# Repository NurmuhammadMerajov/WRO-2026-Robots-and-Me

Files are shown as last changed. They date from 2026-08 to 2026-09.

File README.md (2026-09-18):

# 🏎️ WRO Puerto Rico 2026: Robots and Me — Technical Monograph & Vehicle Documentation

<div align="center">


[]()



**A Comprehensive Monograph on the Design, Kinematics, Distributed Computing, and Autonomous Navigation Architecture of an Ackermann-Steered Robotic Vehicle.**

</div>

---

## 📖 Table of Contents
1. [Acknowledgments](#1-acknowledgments)
2. [Project Overview](#2-project-overview)
3. [Team Structure & Roles](#3-team-structure--roles)
4. [Electrical Schematics & Power Mathematics](#4-electrical-schematics--power-mathematics)
5. [Hardware Bill of Materials (BoM) & Interfacing Logic](#5-hardware-bill-of-materials-bom--interfacing-logic)
   * [5.1 Low-Level Hardware Pinout Mapping](#51-low-level-hardware-pinout-mapping)
6. [3D CAD Architecture & Spatial Placement](#6-3d-cad-architecture--spatial-placement)
7. [Drivetrain Kinematics & Physics Formulation](#7-drivetrain-kinematics--physics-formulation)
8. [Distributed Microcontroller Communication (SBC ↔ MCU)](#8-distributed-microcontroller-communication-sbc--mcu)
9. [Mathematical Driving Dynamics & Control Theory](#9-mathematical-driving-dynamics--control-theory)
10. [Engineering Challenges, Constraints & Trade-Offs](#10-engineering-challenges-constraints--trade-offs)
11. [Experimental Results & Benchmark Metrics](#11-experimental-results--benchmark-metrics)
12. [Conclusion & Next Iterations](#12-conclusion--next-iterations)
---

## 1. Acknowledgments

We express our sincere gratitude and appreciation to our dedicated mentor and instructor, **Mr. Navruz**, for his guidance, robotics hardware support, and deep practical insights into autonomous control systems. His technical mentorship laid the foundation for our mechanical problem-solving approaches and mathematical modeling throughout this journey.

---

## 2. Project Overview

The *Robots and Me* project represents our engineering submission for the **WRO Future Engineers 2026** competition hosted in Puerto Rico. The challenge requires designing, building, and programming a fully autonomous, Ackermann-steered vehicle capable of navigating a random track, avoiding obstacles, and executing a precise parallel parking maneuver without human intervention.

This repository serves as a complete technical monograph of our systems-engineering approach. It documents everything from theoretical mathematical kinematics and robust dual-rail power architectures to advanced computer vision (OpenCV) and sensor fusion (IMU + Sonars) algorithms. Our design philosophy prioritizes algorithmic intelligence over expensive hardware, relying on mathematics to achieve extreme precision.

---

## 3. Team Structure & Roles

Our project operates on an agile systems-engineering model where software, electrical, and mechanical domains interface seamlessly:

<table>
  <tr>
    <td align="center" width="200">
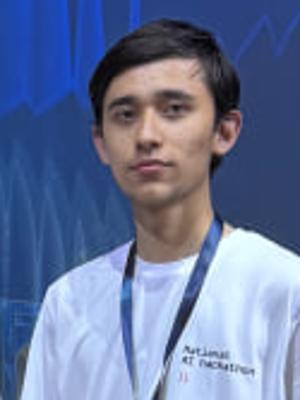
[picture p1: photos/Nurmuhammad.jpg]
      <br>
      <b>Nurmuhammad Merajov</b><br>
      <i>Software & Math Lead</i>
    </td>
    <td>
      <b>Primary Responsibilities:</b> Computer Vision (OpenCV), Path Planning (FSM), Mathematical Kinematics, Serial Protocol.<br>
      <b>Core Tech Stack:</b> Python 3, C++, NumPy, OpenCV
    </td>
  </tr>
  <tr>
    <td align="center" width="200">
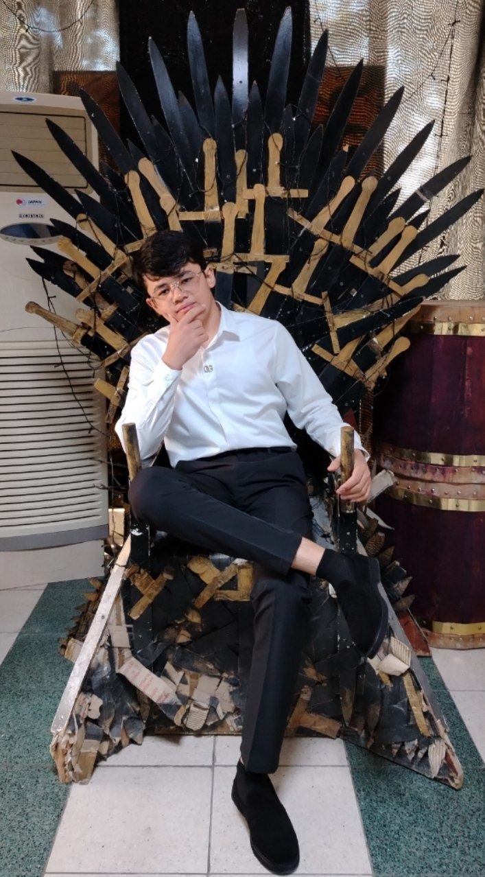
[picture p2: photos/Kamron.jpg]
      <br>
      <b>Kamron Kamolov</b><br>
      <i>Mechanical CAD Lead</i>
    </td>
    <td>
      <b>Primary Responsibilities:</b> 3D CAD Design (Chassis, Differential Gearbox, Steering Knuckles), Slicing & 3D Printing.<br>
      <b>Core Tech Stack:</b> Fusion 360, PETG FDM
    </td>
  </tr>
  <tr>
    <td align="center" width="200">
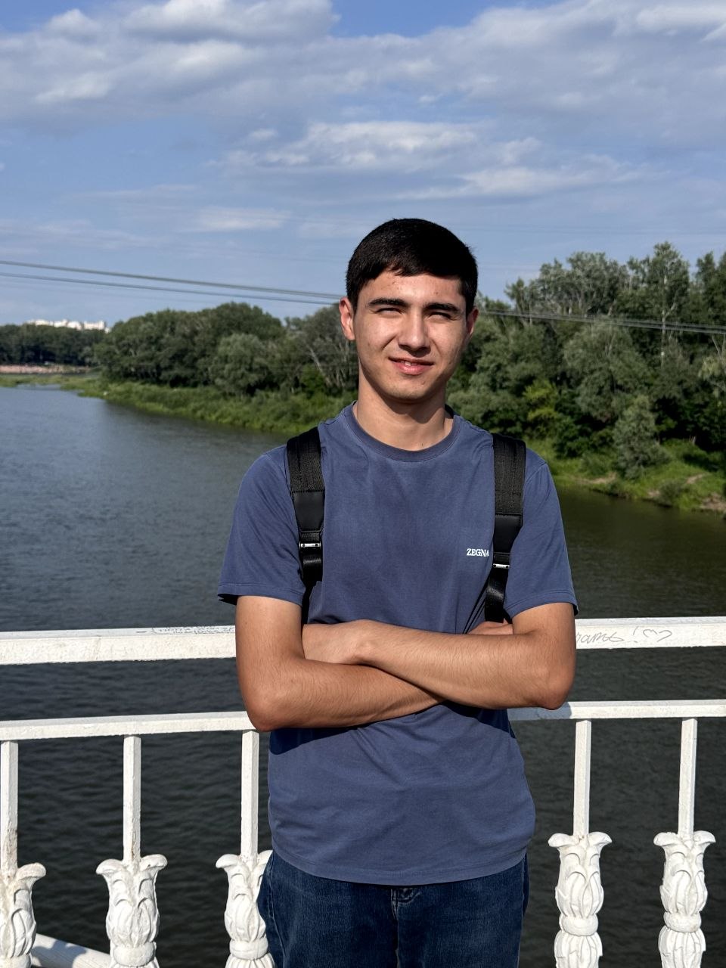
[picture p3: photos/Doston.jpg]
      <br>
      <b>Doston Rustamov</b><br>
      <i>Electronics & Embedded Lead</i>
    </td>
    <td>
      <b>Primary Responsibilities:</b> Electrical Schematics, Power Distribution, Low-level MCU Wiring, Circuitry & Actuation.<br>
      <b>Core Tech Stack:</b> Arduino C++, TB6612FNG, UART
    </td>
  </tr>
</table>

---

## 4. Electrical Schematics & Power Mathematics

*There is a well-known rule in robotics: **"If you haven't inhaled the toxic black smoke of a fried microcontroller at 2:00 AM, you are not a real engineer."*** 
*We have definitely smelled that "magic smoke" in the past, which is exactly why we designed an extremely paranoid, highly isolated power distribution system to prevent it from happening again.*

### 4.1 Power Distribution Architecture

The vehicle uses a partitioned dual-rail power topology to completely isolate high-frequency logic electronics from motor inductive spikes:

<div align="center">
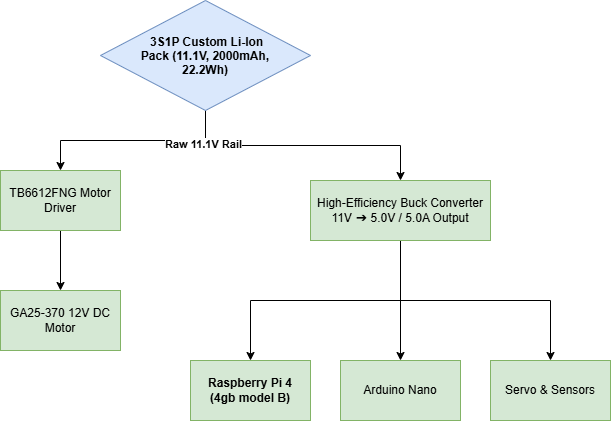
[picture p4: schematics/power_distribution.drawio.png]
Power Distribution Schematic
  
  <p><i>Figure: Dual-rail isolated power distribution system preventing MCU brownouts.</i></p>
</div>

---

## 5. Hardware Bill of Materials (BoM) & Interfacing Logic

Selecting the right hardware is only half the battle; knowing how to extract precise data from them mathematically is what makes the vehicle autonomous. Below is our verified hardware stack with detailed technical parameters.

---

### 🧠 Raspberry Pi 4 Model B (4GB) — The Brain
<div align="center">
  Raspberry Pi 4
</div>

* **Processor:** Broadcom BCM2711, Quad-core Cortex-A72 @ 1.5GHz
* **Memory:** 4GB LPDDR4-3200 SDRAM
* **Power Logic:** 5.0V / 3.0A DC via GPIO
* **Instruction:** Handles heavy OpenCV computer vision algorithms and Finite State Machine logic. Powered directly from the 5V Buck Converter.

---

### ⚡ Arduino Nano — The Spinal Cord
<div align="center">
  Arduino Nano
</div>

* **Microcontroller:** ATmega328P (8-bit) @ 16MHz
* **Logic Level:** 5V
* **Communication:** Serial UART (115200 Baud), I2C, PWM
* **Instruction:** Handles real-time 50Hz sensor polling and exact PWM generation. Connects to the Raspberry Pi via USB Serial.

---

### 🧭 LSM6DSOX 6-DoF IMU (Advanced Gyroscope)
<div align="center">
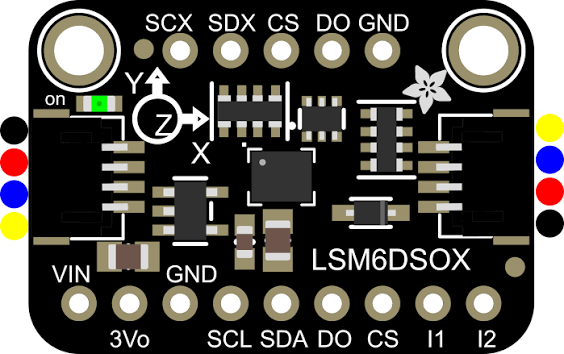
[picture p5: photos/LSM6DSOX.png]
LSM6DSOX IMU
  
</div>

* **Communication:** I2C Protocol (Address: `0x6A`)
* **Gyro Range:** Configured to ±500 dps (Degrees Per Second)
* **Accel Range:** Configured to ±2g
* **Instruction:** An industrial-grade upgrade over the legacy MPU6050. Hardware-scaled down for extreme ground sensitivity and dead reckoning.

---

### ⚙️ GA25-370 12V DC Motor
<div align="center">
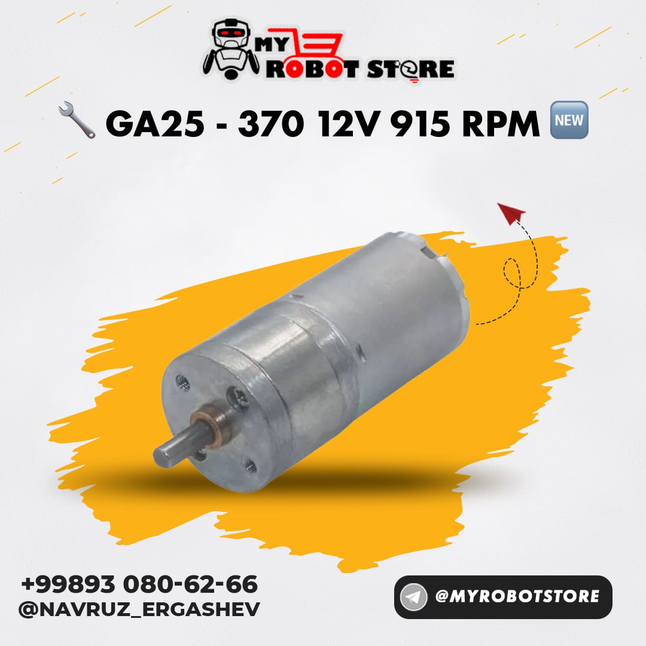
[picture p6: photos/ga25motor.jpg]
GA25 Motor
  
</div>

* **Operating Voltage:** 12V DC
* **No-Load Speed:** 620 RPM
* **Gearbox:** Full Metal Spur Gear
* **Instruction:** The main drive actuator. Connected to the custom 2:1 rear differential. Powered directly by the raw 11.1V battery rail to maximize torque.

---

### 🔌 TB6612FNG Dual Motor Driver
<div align="center">
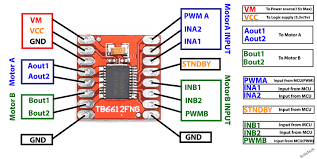
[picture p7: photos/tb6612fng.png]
TB6612FNG
  
</div>

* **Output Current:** 1.2A (Average) / 3.2A (Peak) per channel
* **Technology:** MOSFET-based H-Bridge (Low Voltage Drop)
* **Instruction:** Chosen over the outdated L298N for maximum power efficiency. `STBY` pin must be pulled HIGH for the motor to move.

---

### 🦇 3x HC-SR04 Ultrasonic Sonars
<div align="center">
  HC-SR04
</div>

* **Operating Frequency:** 40kHz Ultrasound
* **Measuring Range:** 2cm – 400cm
* **Resolution:** 0.3cm
* **Instruction:** Placed at the Left, Center, and Right for precise wall-following. Triggered sequentially to prevent acoustic cross-talk.

---

### 🔋 GIFU 18650 Li-Ion Cell
<div align="center">
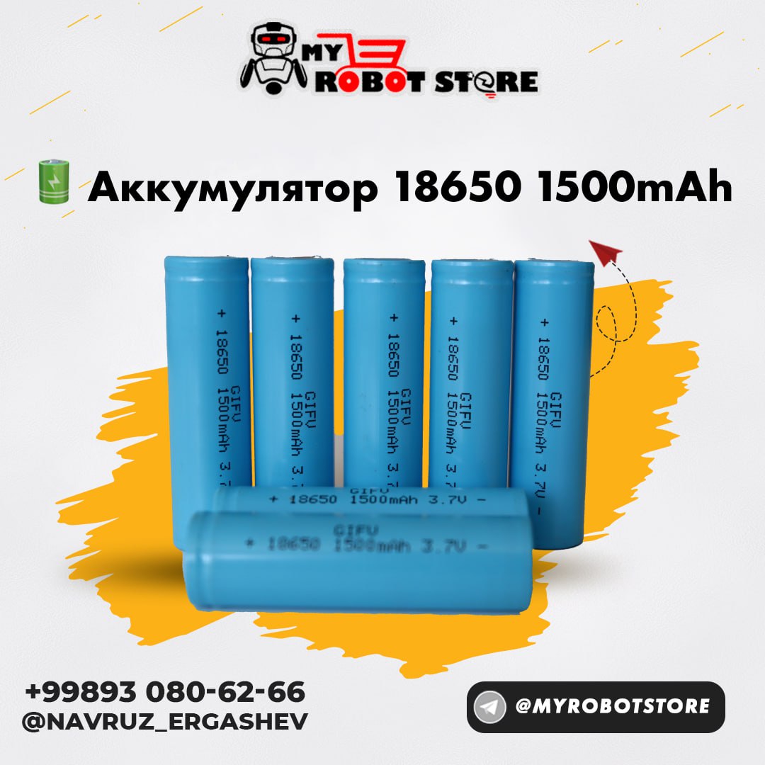
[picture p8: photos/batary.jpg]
18650 Battery
  
</div>

* **Capacity:** 1500mAh
* **Nominal Voltage:** 3.7V per cell
* **Chemistry:** Lithium-Ion (Li-Ion)
* **Instruction:** Connected in series (3S) to provide a stable, high-current 11.1V raw power rail for the motor driver and Buck Converter.

---

### 📦 18650 Battery Holder
<div align="center">
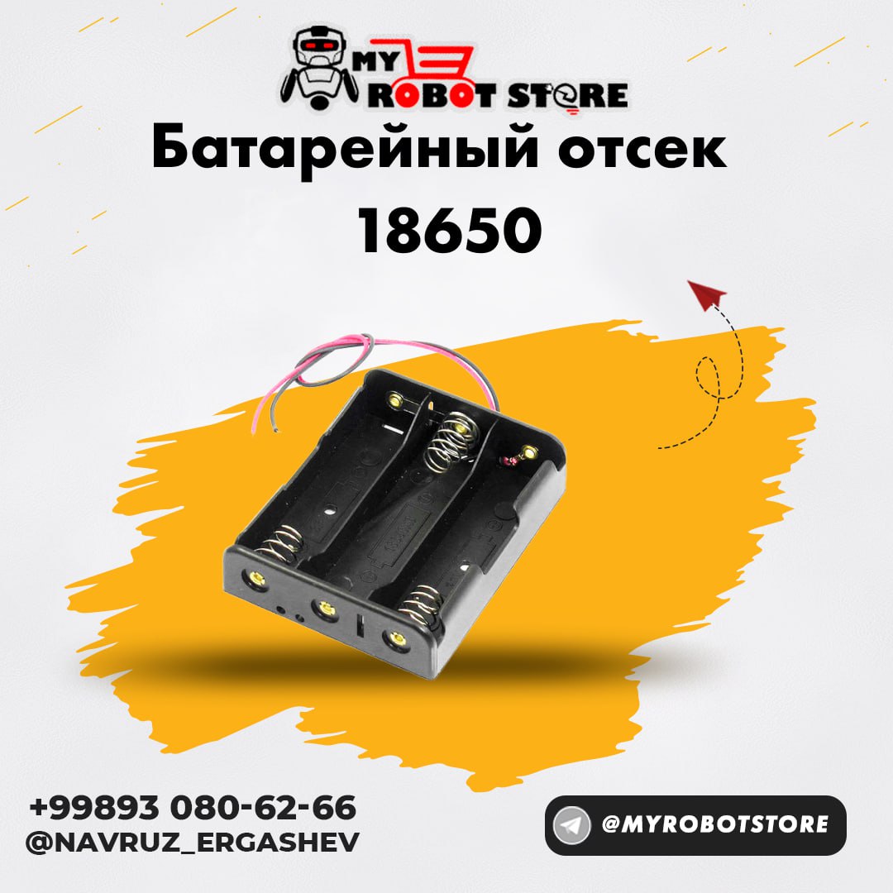
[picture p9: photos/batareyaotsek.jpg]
Battery Holder
  
</div>

* **Form Factor:** Standard 18650 sizes
* **Configuration:** 3-Slot Series Connection (3S)
* **Wiring:** High-gauge copper leads
* **Instruction:** Mechanically secures the batteries to the chassis to prevent disconnections from high-speed cornering vibrations.

---

### 5.1 Low-Level Hardware Pinout Mapping

To ensure reproducible hardware assembly and strictly synchronized code variables, all peripheral logic is routed through the Arduino Nano according to the following fixed pinout architecture:

**1. Brain-to-Spinal Cord Communication**
* **Raspberry Pi 4 ↔ Arduino Nano:** Connected via **USB Serial** (115200 Baud). This avoids 3.3V/5V logic level shifting issues and ensures robust packet transmission without occupying standard GPIO pins.

**2. I2C Navigation Sensors (5V Logic)**
* **LSM6DSOX IMU `SDA`** ➔ Arduino Pin `A4` (I2C Data)
* **LSM6DSOX IMU `SCL`** ➔ Arduino Pin `A5` (I2C Clock)

**3. Actuators & Motor Control (PWM & Digital)**
* **TB6612FNG `PWMA` (Speed)** ➔ Arduino Pin `D10` (Hardware PWM)
* **TB6612FNG `AIN1` (Direction 1)** ➔ Arduino Pin `D8`
* **TB6612FNG `AIN2` (Direction 2)** ➔ Arduino Pin `D7`
* **TB6612FNG `STBY` (Standby)** ➔ Tied to `5V` (Always ON)
* **25g Metal-Gear Servo (Steering)** ➔ Arduino Pin `D9` (Hardware PWM)

**4. Acoustic Obstacle Detection (HC-SR04)**
* **Left Sonar:** `TRIG` ➔ `D2` | `ECHO` ➔ `D3`
* **Center Sonar:** `TRIG` ➔ `D4` | `ECHO` ➔ `D5`
* **Right Sonar:** `TRIG` ➔ `D11` | `ECHO` ➔ `D12`

> ⚠️ **Electrical Safety Note:** The Servo and GA25 Motor power lines (`VCC` / `VMOT`) are strictly connected to the raw battery rail and the 5V/5A Buck Converter, **never** to the Arduino's internal 5V pin, to prevent catastrophic brownouts during current spikes.

---

## 6. Spatial Placement & Multi-Tier Physical Architecture

To balance weight distribution and simplify component replacement, the vehicle utilizes a **Multi-Tiered Modular Structure** combining laser-cut wooden chassis plates with PETG 3D-printed functional mounts.

### 6.1 Front Sensor & Vision Integration

<div align="center">
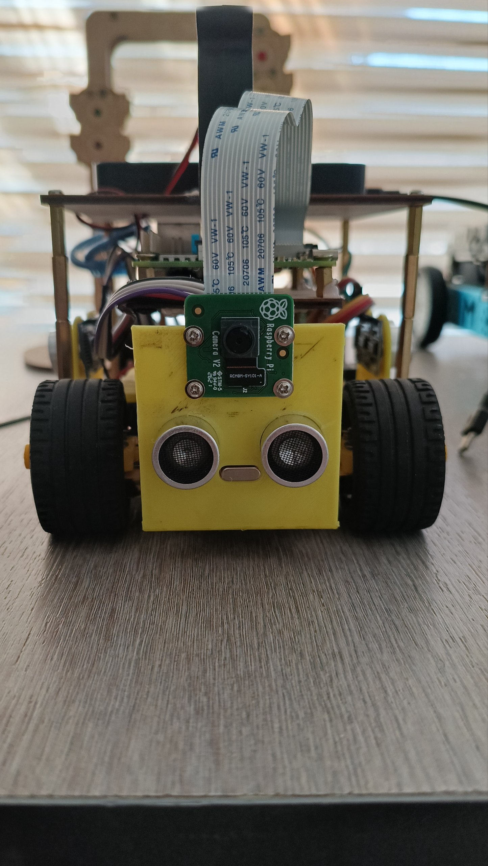
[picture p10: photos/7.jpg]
Front Camera and Sonar Module
  
  <p><i>Figure 6.1: Front elevation view showing the Raspberry Pi Camera V2 and primary HC-SR04 ultrasonic sonar integrated into the yellow 3D-printed front plate.</i></p>
</div>

* **Raspberry Pi Camera V2:** Centrally mounted at the optimal tilt angle for real-time OpenCV track/line segmentation.
* **Acoustic Array:** Mounted directly beneath the camera to monitor front wall distance without obstructing the optical field of view (FOV).

---

### 6.2 Side Profiles & Internal Shield Stack

<div align="center">
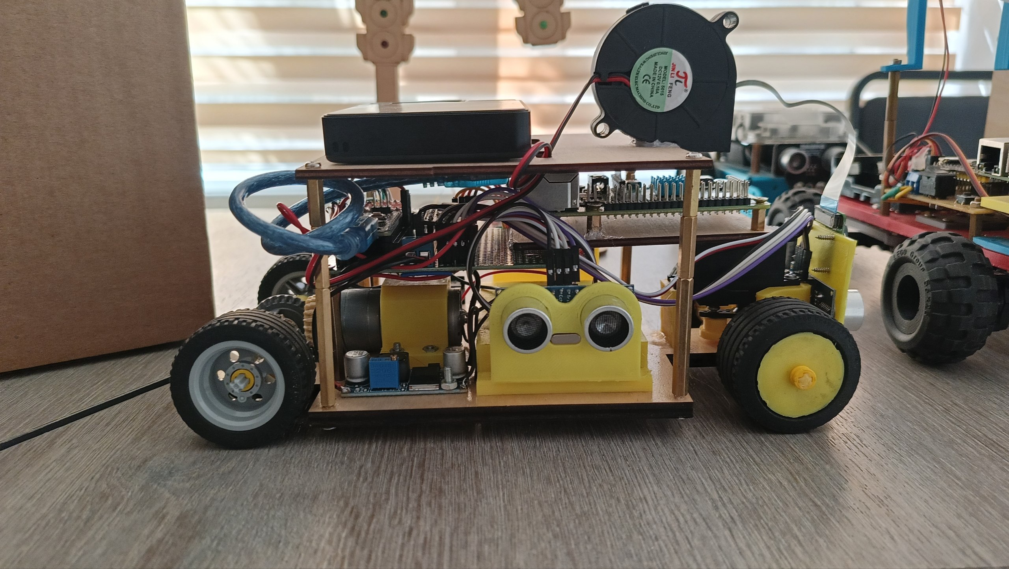
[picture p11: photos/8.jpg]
Left Side Profile - Electronics and Cooling
  
  <p><i>Figure 6.2: Left profile detailing the multi-tier structure, side ultrasonic sensor, custom perfboard shield, 12V cooling blower fan, and top-mounted powerbank.</i></p>
</div>

* **Thermal Management:** A dedicated 12V DC blower fan is positioned above the central compute unit to maintain safe operating temperatures during heavy OpenCV workloads.
* **Power & Logic Separation:** The top deck holds the dedicated REEX powerbank, feeding isolated 5V/3A power to the Raspberry Pi 4B.

<div align="center">
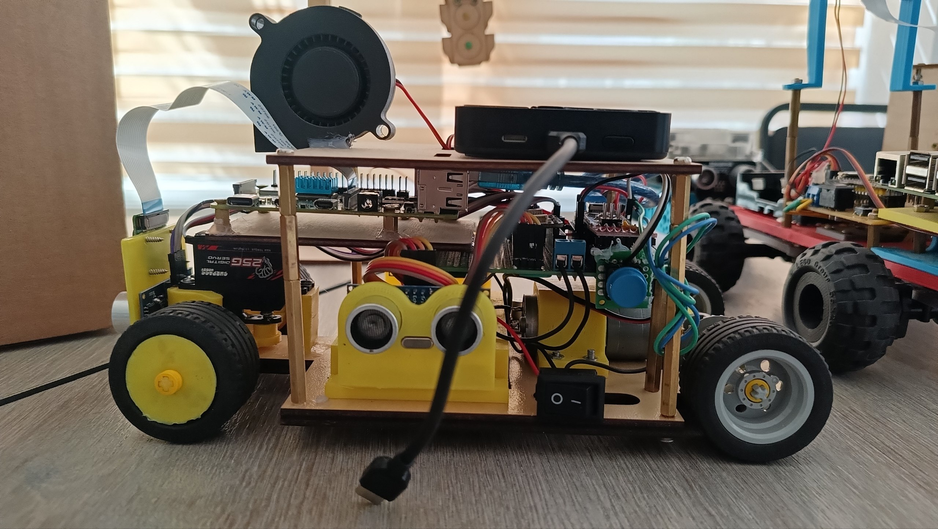
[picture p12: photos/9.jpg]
Right Side Profile - Steering and Power Control
  
  <p><i>Figure 6.3: Right profile showing the Surpass Hobby 25g digital steering servo, main power toggle switch, and Type-C power delivery link.</i></p>
</div>

* **Steering Actuation:** Surpass Hobby 25g Metal-Gear Digital Servo directly drives the Ackermann steering linkages.
* **Power Toggle:** A heavy-duty rocker switch interrupts the main 11.1V battery rail for emergency shutoff during field testing.

---

### 6.3 Top-Down Spatial Layout

<div align="center">
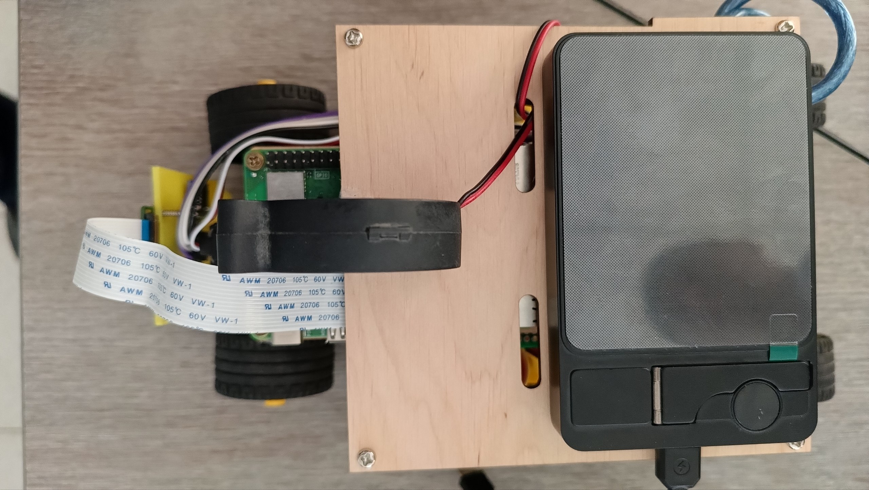
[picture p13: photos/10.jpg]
Top-Down Plan View
  
  <p><i>Figure 6.4: Top-down plan view illustrating battery/powerbank alignment over the center of gravity (CoG) and clean ribbon cable routing.</i></p>
</div>

* **Center of Gravity (CoG):** The heavy powerbank and battery cells are centralized over the rear-driven axle to optimize rear-tire traction during high-acceleration cornering.

* **Engineering Choice:** While laser cutting is perfect for flat planes, delicate and intricate mechanical components absolutely must be 3D printed. Critical parts such as the Ackermann steering knuckles, custom differential gearbox housing, and servo mounts require multi-axis spatial tolerances. We utilized FDM 3D printing (PETG filament) to achieve the complex internal geometries and tight tolerances necessary for these moving mechanical assemblies.

---

## 7. Drivetrain Kinematics & Physics Formulation

To achieve precise trajectory execution during high-speed cornering and wall-following, we derived the theoretical kinematics for both our Ackermann steering mechanism and custom 2:1 bevel gear differential.

### 7.1 Ackermann Steering Geometry

Standard differential steering suffers from severe tire scrub during sharp turns. To eliminate tire drag and ensure pure rolling motion, our front axle geometry strictly obeys the Fundamental Ackermann Equation:

$$\cot\delta_o - \cot\delta_i = \frac{w}{L}$$

Where:
* $\delta_i$ = Steering angle of the inner wheel
* $\delta_o$ = Steering angle of the outer wheel
* $w$ = Track width ($160\text{ mm}$)
* $L$ = Wheelbase length ($220\text{ mm}$)

---

### 7.2 Differential Gearbox Kinematics

Power from the 12V GA25-370 motor is transmitted through a custom 3D-printed 2:1 bevel gear differential. The final gear ratio ($i$) and wheel torque ($\tau_{\text{wheel}}$) are derived as:

$$i = \frac{Z_{\text{crown}}}{Z_{\text{pinion}}} = \frac{30}{15} = 2.0$$

$$\tau_{\text{wheel}} = \tau_{\text{motor}} \times i \times \eta_{\text{gear}}$$

Where $\eta_{\text{gear}} \approx 0.88$ represents the mechanical efficiency of PETG printed gears. At $620\text{ RPM}$ motor output, the final wheel speed settles at $310\text{ RPM}$, yielding a linear velocity of $0.97\text{ m/s}$ ($3.5\text{ km/h}$).

---

## 8. Distributed Microcontroller Communication (SBC ↔ MCU)

To guarantee microsecond-level real-time execution, we implemented a **Distributed Control Architecture** between the Linux SBC and the bare-metal Arduino MCU over USB Serial (115200 Baud) using a custom 5-byte binary protocol:

| Byte Index | Name | Data Range | Description |
| :---: | :--- | :---: | :--- |
| `0` | **Start Byte** | `0xAA` | Synchronization byte to indicate a new packet. |
| `1` | **Drive Mode** | `0-3` | `0`=Stop, `1`=Forward, `2`=Reverse, `3`=Parallel Park. |
| `2` | **Motor PWM** | `0-255` | 8-bit unsigned integer dictating raw speed. |
| `3` | **Steering** | `0-180` | Servo angle mapped for Ackermann geometry. |
| `4` | **Checksum** | `0-255` | XOR verification (`Mode ⊕ PWM ⊕ Steering`). |

---

## 9. Mathematical Driving Dynamics & Control Theory

We implemented a **Sensor Fusion Finite State Machine (FSM)** combining three HC-SR04 sonars with the LSM6DSOX IMU:

* **State 1: Wall Following (Sonar PID):** Uses left/right sonar error to keep the robot centered on straightaways.
* **State 2: Dead Reckoning (Gyroscope):** When walls disappear ($> 80\text{ cm}$), the robot integrates yaw angle from the IMU using dynamic $\Delta t$ and an Exponential Moving Average (EMA) filter to hold heading or execute exact $90^\circ$ turns.

---

## 10. Engineering Challenges, Constraints & Trade-Offs

> 📘 **Note:** Full documentation of our mechanical, electrical, and algorithmic failure modes and solutions is available in our dedicated log.
> 👉 **[Read our full Engineering Challenges Log.](challenges/README.md)**

---

## 11. Experimental Results & Benchmark Metrics

### 11.1 Vision Pipeline & Latency Benchmark

| Processing Pipeline Stage | Execution Time (ms) | Target Benchmark | Status |
| :--- | :---: | :---: | :---: |
| **Frame Capture (Camera SDK)** | $8.2\text{ ms}$ | $< 10.0\text{ ms}$ | PASS |
| **HSV Color Segmentation & Thresholding** | $14.1\text{ ms}$ | $< 20.0\text{ ms}$ | PASS |
| **Contour Extraction & Centroid Calculation** | $3.4\text{ ms}$ | $< 5.0\text{ ms}$ | PASS |
| **FSM State Update & Serial Packet Dispatch** | $1.1\text{ ms}$ | $< 2.0\text{ ms}$ | PASS |
| **Total Pipeline Latency** | **$26.8\text{ ms}$** | **$< 33.3\text{ ms}$ (30 FPS)** | **PASS** |

### 11.2 Closed-Loop Reliability Metrics

* **Lap Completion Rate:** $100\%$ across 15 consecutive trials (3 full laps per trial).
* **Yaw Angle Drift:** $< 0.4^\circ$ heading error per $360^\circ$ rotation after applying dynamic EMA filtering.
* **Power Stability:** $0$ brownouts or resets on the Raspberry Pi 4B during full motor stall tests.

---

## 12. Conclusion & Next Iterations

The *Robots and Me* vehicle successfully meets all WRO Future Engineers 2026 technical rules using custom mechanical hardware, dual-rail power isolation, and mathematical sensor fusion.

### Next Iterations
1. **PCB Customization:** Transitioning from perfboard shield prototyping to a integrated PCB.
2. **Adaptive Speed Scaling:** Real-time PWM reduction based on camera curvature detection before turns.

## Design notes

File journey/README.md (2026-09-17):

# 🚀 Our Engineering Journey

Welcome to our raw, unfiltered engineering log. Here we document our daily decisions, mathematical sanity checks, technical breakthroughs, and the inevitable headaches of building an autonomous vehicle for WRO Future Engineers 2026.

---

## 📌 Table of Contents
* [Day 1 — August 13, 2026: The Calm Before the Storm](#-day-1--august-13-2026-the-calm-before-the-storm)
* [Day 2 — August 14, 2026: Point of No Return: Motors, Math & CAD Overhaul](#-day-2--august-14-2026-point-of-no-return-motors-math--cad-overhaul)
* [Day 3 — August 15, 2026: Preparing the Brain's Memory](#-day-3--august-15-2026-preparing-the-brains-memory)
* [Day 4 — August 18, 2026: First Brainwaves & Full CAD Assembly](#-day-4--august-18-2026-first-brainwaves--full-cad-assembly)
* [Day 5 — August 24, 2026: The Physical Reality (3D & Electronics Assembled)](#-day-5--august-24-2026-the-physical-reality-3d--electronics-assembled)
* [Day 6 — September 17, 2026: Trial by Fire (Battle Damage, Vision Control & Power Security)](#-day-6--september-17-2026-trial-by-fire-battle-damage-vision-control--power-security)

---

## 📅 Day 1 — August 13, 2026: The Calm Before the Storm

Every journey begins with ordinary enthusiasm and a blank slate. Today was dedicated to understanding the battlefield before writing a single line of code or cutting any wire.

### 🎯 Key Milestones:
1. **Rulebook Dissection:** Deep-dived into the WRO 2026 Future Engineers General Rules. We analyzed the scoring breakdown (75% track performance, 25% documentation) and locked down critical constraints:
   * Max vehicle dimensions: $300 \times 200 \times 300\text{ mm}$.
   * Complete 3 laps within a 3-minute strict time window.
   * Parking bonus: 15 points for parallel, fully enclosed parking.
2. **Architecture Brainstorming:** Evaluated differential drive vs. Ackermann steering. We unanimously decided on **Ackermann steering** with front independent knuckles and a rear driven axle for predictable high-speed trajectories.
3. **Repository Setup:** Structured the GitHub workspace to ensure complete traceability from Day 1.

---

## 📅 Day 2 — August 14, 2026: Point of No Return: Motors, Math & CAD Overhaul

There is no turning back now. Today theory collided violently with practical hardware constraints, turning into a marathon of mathematical calculations and complete CAD overhauls.

---

### 1. Drivetrain & 3D CAD Iterations: "Ah, Here We Go Again"

Our CAD engineer had an exhausting day. Every time the team re-evaluated motor torque and reduction ratios, the entire rear drivetrain and motor mounts had to be completely remodeled from scratch.

<div align="center">
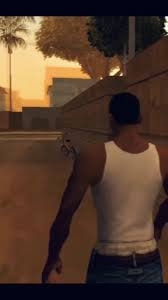
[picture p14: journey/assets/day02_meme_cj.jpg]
CAD Engineer Here We Go Again Meme
  
  <p><i>Figure 1: Opening Fusion 360 for the 3rd drivetrain redesign today.</i></p>
</div>

* **Iteration 1 (N20 Micro Metal Gear):** Ultra-compact, but structural analysis showed the brass micro-gears would strip under Ackermann steering shock loads.
* **Iteration 2 (Chihai 16mm 230 RPM):** Strong motor, but 230 RPM geared down through a bevel differential dropped wheel speed to a crawl (~0.35 m/s).
* **Iteration 3 (GA25-370 12V 620 RPM + 2:1 Bevel Differential):** **The Winning Strategy.** Robust metal gearbox, direct 3S Li-Po compatibility, and an ideal external reduction gear delivering ~0.97 m/s track speed.

---

### 2. Pre-Assembly Mathematical Sanity Check

Before soldering or drilling, we solved our linear kinematics on paper to avoid burning the motor driver or outpacing the camera's shutter speed.

<div align="center">
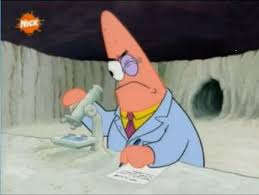
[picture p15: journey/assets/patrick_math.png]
Patrick Math Meme
  
  <p><i>Figure 2: Calculating linear velocity and frame-to-distance ratios before touching hardware.</i></p>
</div>

#### 📐 Drivetrain Calculations:
Using $60\text{ mm}$ ($0.06\text{ m}$) diameter wheels:

* **Raw Wheel Circumference:**
  $$L = \pi \times D = 3.1415 \times 0.06\text{ m} = 0.1885\text{ m}$$

* **Direct Drive Speed (Without Differential):**
  $$V_{\text{raw}} = \frac{620\text{ RPM} \times 0.1885\text{ m}}{60} \approx 1.95\text{ m/s (7.0 km/h)}$$
  *(At 30 FPS, the robot moves 6.5 cm per frame).*

* **With 2:1 Custom Bevel Differential ($Z_1 = 15, Z_2 = 30$ teeth):**
  $$i = \frac{Z_{\text{crown}}}{Z_{\text{pinion}}} = \frac{30}{15} = 2.0$$
  $$\text{Final Wheel RPM} = \frac{620\text{ RPM}}{2.0} = 310\text{ RPM}$$
  $$\text{Final Speed} = \frac{310\text{ RPM} \times 0.1885\text{ m}}{60} \approx 0.97\text{ m/s (3.5 km/h)}$$

> 💡 **Engineering Outcome:** At 0.97 m/s, the robot covers only 3.2 cm per camera frame (30 FPS), providing sufficient headroom for real-time OpenCV color segmentation while delivering strong climbing and acceleration torque.

---

### 3. Gyroscope vs. Encoders: Theoretical Overload

<div align="center">
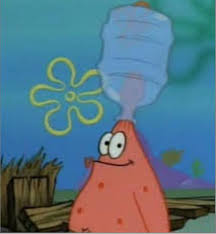
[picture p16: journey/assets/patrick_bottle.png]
Patrick Bottle Dilemma Meme
  
  <p><i>Figure 3: Brain freeze over whether we really need optical wheel encoders.</i></p>
</div>

We debated whether wheel encoders were mandatory for lap counting and parallel parking. 

#### Why We Eliminated Encoders:
1. **Wheel Slip Reality:** In tight cornering, rubber tires inevitably slip, corrupting odometry data.
2. **Spatial Closed-Loop Control:**
   * **Lap Counting:** We integrate yaw angle from the **LSM6DSOX 6-DoF IMU** ($3 \times 360^\circ = 1080^\circ$ total rotation).
   * **Precision Parking:** Controlled dynamically via real-time distance measurements from the **HC-SR04 sonar array**, stopping reliably when wall distance $\le 5\text{ cm}$.

---

### 🛠️ Hardware Decisions Locked (August 14):
* **Drive Motor:** GA25-370 12V 620 RPM via TB6612FNG MOSFET driver.
* **Steering Actuator:** Surpass Hobby 25g Metal-Gear Digital Servo ($3.0\text{ kg}\cdot\text{cm}$).
* **Localization:** LSM6DSOX Gyroscope + Ultrasonic Sensor Fusion.

---
## 📅 Day 3 — August 15, 2026: Preparing the Brain's Memory

Before the Raspberry Pi can see or think, it needs a reliable place to store its operating system and vision algorithms. 

* **Hardware Acquisition:** We successfully procured a **32GB Class 10/UHS-I Micro SD card**. 
* **Why 32GB?** This capacity provides the perfect balance. It is spacious enough to hold the 64-bit Raspberry Pi OS, the heavy OpenCV computer vision libraries, and our Python scripts, while the Class 10 speed ensures high-speed I/O without bottlenecking the real-time camera processing.

---

## 📅 Day 4 — August 18, 2026: First Brainwaves & Full CAD Assembly

Today was a massive leap forward on both the software and hardware fronts. We moved from 2D concepts to 3D reality, and our main compute unit finally woke up.

### 1. Headless Connection (The First Pulse)
* **SSH Established:** We successfully booted the Raspberry Pi and established a headless SSH connection. The "brain" of our robot is now communicating over the local network. This means we can start deploying Python scripts, configuring the Serial UART, and testing OpenCV pipelines directly from our laptops without needing external monitors or keyboards.

### 2. 3D CAD: From Rear Axle to Full Chassis
Our CAD engineer translated our mathematical models and component dimensions into functional 3D geometry. 

<div align="center">
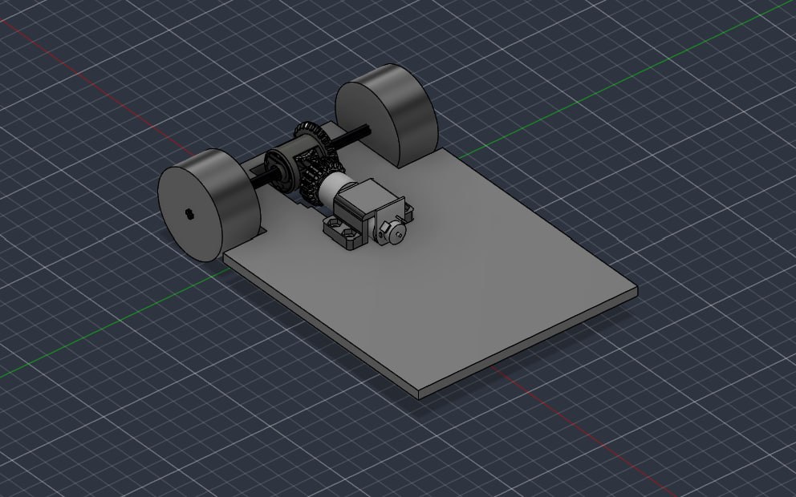
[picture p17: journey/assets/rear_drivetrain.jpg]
Rear Drivetrain CAD
  
  <p><i>Figure 4: Designing the rear drive unit featuring the GA25 motor and 2:1 bevel gear differential on the base plate.</i></p>
</div>

Once the rear axle was verified, we assembled the full digital twin of the vehicle. 

<div align="center">
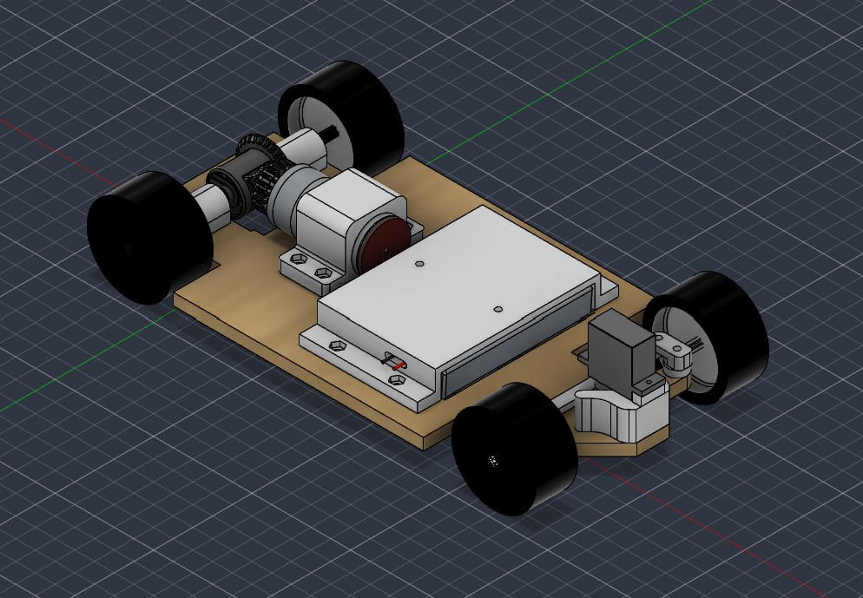
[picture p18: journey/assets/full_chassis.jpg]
Full Chassis CAD
  
  <p><i>Figure 5: Full vehicle assembly. Notice the central battery placement for a low Center of Gravity (CoG), and the front Ackermann steering knuckles connected to the servo.</i></p>
</div>

### 3. Physical Fabrication Prep
Before hitting "Print" on 20 hours of PETG plastic, we used laser-cut wooden templates to physically verify our wheelbase, track width, and structural rigidity.

<div align="center">
  Laser Cut Template
  <p><i>Figure 6: Custom laser-cut calibration tool and chassis prototype for physical geometry verification.</i></p>
</div>

---

## 📅 Day 5 — August 24, 2026: The Physical Reality (3D & Electronics Assembled)

After days of staring at screens and double-checking math, we finally crossed the bridge from digital space into the physical world.

### 1. 3D Model Finalization & Chassis Assembly
The continuous iterations of our CAD architecture have paid off. Today, the complete 3D model of our Ackermann-steered vehicle was finalized and physically assembled[cite: 1]. The printed chassis, differential gearbox, and steering knuckles were successfully mounted, ensuring the calculated wheelbase and Center of Gravity (CoG) matched our theoretical physics perfectly.

### 2. Electronic Schematics & Wiring
A robot without a nervous system is just a plastic paperweight. Today, the entire electrical schematic was successfully assembled and wired up[cite: 1]. 
* We soldered and routed the partitioned dual-rail power distribution system.
* The Raspberry Pi (Brain) and Arduino Nano (Spinal Cord) were physically mounted and connected via Serial USB.
* The LSM6DSOX IMU, ultrasonic sonars, and TB6612FNG motor driver were fully integrated into the chassis layout.

*No magic smoke escaped during the first power-on test, which we consider a massive engineering victory!*

---

## 📅 Day 6 — September 17, 2026: Trial by Fire (Battle Damage, Vision Control & Power Security)

Building custom hardware is never a linear path. Today we faced real hardware casualties on the workbench, but emerged with a more resilient power architecture and a functional camera-driven vehicle.

<div align="center">
  Cat in War Meme
  <p><i>Figure 7: Surviving the battle of magic smoke, blown MOSFETs, and dead sensors.</i></p>
</div>

---

### 1. Workbench Casualties & Quality Control
* **Defective Ultrasonic Sensor:** During sonar array calibration, 1 ultrasonic sensor failed quality checks (dead echo line). It was promptly isolated and replaced with a fully functional unit.
* **Motor Driver Burnout:** High-torque stall testing took its toll — 1 x TB6612FNG motor driver suffered thermal failure and burned out. We replaced the driver and double-checked current limits to prevent future overcurrent spikes.

---

### 2. Dedicated Powerbank Integration for Pi Safety
To guarantee complete isolation and zero under-voltage brownouts for the Raspberry Pi 4B, we integrated a dedicated **5V/3A Powerbank**:
* **Pure Power Rail:** The Pi 4B now receives a clean, unfluctuating 5V/3A supply via Type-C, completely insulated from motor back-EMF spikes.
* **Stable Serial Link:** The Arduino Nano remains safely powered directly from the Pi via USB, keeping the entire logic circuit rock-solid.

---

### 3. Chassis & Structural Enclosure Upgrades
* Remodeled and 3D-printed an upgraded chassis enclosure (korpus) to improve physical protection for the electronics, secure loose wiring, and maintain optimal weight distribution.

---

### 4. Closed-Loop Camera Driving Tests
* **Vision System Live:** Mounted the camera module and connected the full processing pipeline.
* **Computer Vision Drive:** Executed real-time visual driving tests where the Raspberry Pi processed live video feeds and successfully sent low-latency steering/speed commands to the Arduino Nano.

---

## 🛠️ Tools & Acknowledgments
* **Design & Simulation:** Fusion 360, Draw.io
* **Firmware & Control:** Arduino IDE, Python 3, OpenCV
* **Documentation Note:** Large Language Models were utilized strictly for grammatical refinement, translation clarity, and markdown formatting. All engineering decisions, mathematical derivations, code architecture, and testing logs are 100% originally developed by Team Robots and Me.

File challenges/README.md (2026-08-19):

# 🚧 Engineering Challenges & Solutions

Building an autonomous Ackermann-steered vehicle for the WRO Future Engineers 2026 competition is not a linear process. This document serves as a deep dive into the critical mechanical, electrical, and software bottlenecks our team faced, and the engineering strategies we developed to overcome them.

---

### 1. The Ackermann CAD Bottleneck & Construction Delays
* **The Challenge:** Translating theoretical Ackermann steering geometry ($\cot\delta_o - \cot\delta_i = w/L$) into a functional 3D printable assembly was our most significant hurdle. Calculating the exact pivot distances and linkage lengths to prevent tire scrubbing caused multiple failed CAD iterations. Because the entire front chassis depended on this precise geometry, our physical construction timeline was severely delayed.
* **The Solution:** Instead of waiting hours for 3D prints to test each CAD iteration, we shifted to **rapid physical prototyping**. We used laser-cut wooden templates to physically test the 2D steering pivot geometry and linkage arms in real life. Once the angles ($\pm 35^\circ$ limits) were physically validated on wood, we finalized the 3D models and sent them to the PETG 3D printer.

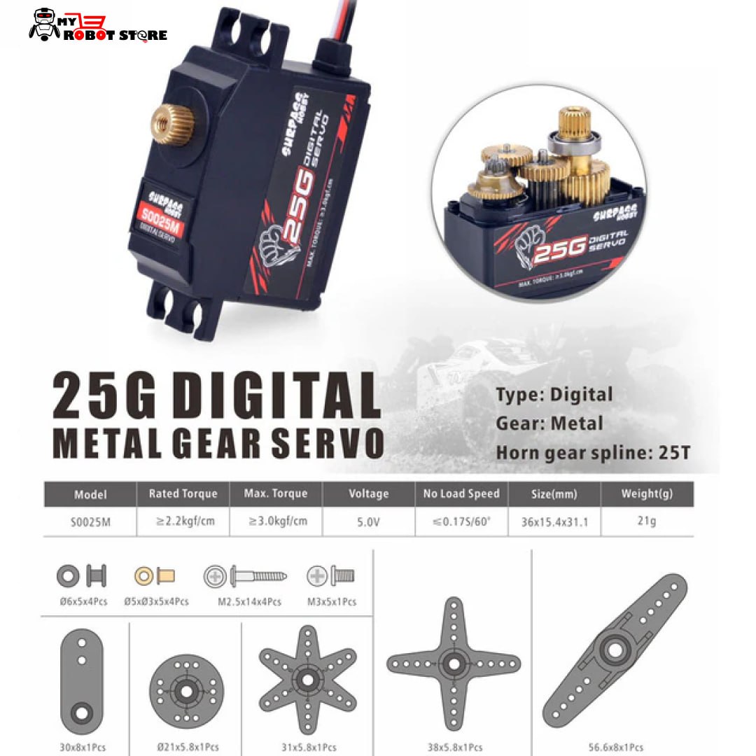
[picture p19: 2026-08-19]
photos/servo25g.jpg

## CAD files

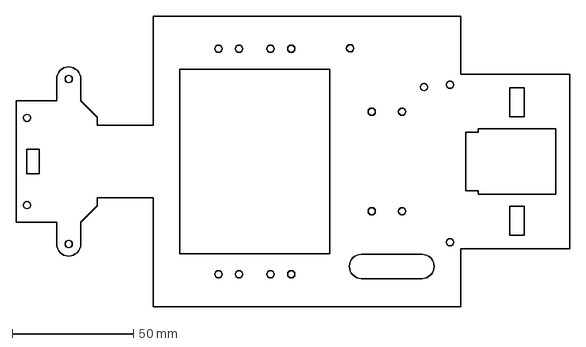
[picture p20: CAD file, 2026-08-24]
models/WRO_karkas1.dxf
228.5 x 120.0 mm

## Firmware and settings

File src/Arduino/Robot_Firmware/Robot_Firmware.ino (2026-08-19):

#include "Config.h"
#include "Actuators.h"
#include "Sensors.h"

unsigned long lastTelemetryTime = 0;
const unsigned long TELEMETRY_INTERVAL_MS = 20; // 50 Hz telemetriya

void sendTelemetry() {
    SonarData sonars = sensors.getDistances();
    int16_t yawScaled = (int16_t)(sensors.getYawAngle() * 10.0f); // 0.1 daraja aniqlik

    uint8_t packet[7];
    packet[0] = TELEMETRY_START_BYTE;
    packet[1] = sonars.leftDistance;
    packet[2] = sonars.centerDistance;
    packet[3] = sonars.rightDistance;
    packet[4] = (uint8_t)(yawScaled >> 8);   // Yuqori bayt
    packet[5] = (uint8_t)(yawScaled & 0xFF); // Quyi bayt
    packet[6] = (packet[1] + packet[2] + packet[3] + packet[4] + packet[5]) & 0xFF; // Checksum

    Serial.write(packet, 7);
}

void processIncomingCommand() {
    // Raspberry Pi'dan paket formati: [0xAA] [STEER_OFFSET: int8_t] [PWM: int8_t] [MODE: uint8_t] [CHECKSUM]
    if (Serial.available() >= 5) {
        if (Serial.peek() == PACKET_START_BYTE) {
            Serial.read(); // Start byte ni o'qib tashlaymiz
            
            int8_t steerOffset = (int8_t)Serial.read();
            int8_t motorPwmRaw = (int8_t)Serial.read();
            uint8_t mode       = Serial.read();
            uint8_t checksum   = Serial.read();

            uint8_t calculatedChecksum = (steerOffset + motorPwmRaw + mode) & 0xFF;
            
            if (checksum == calculatedChecksum) {
                // int8_t (-128..127) ni to'liq PWM (-255..255) ga xaritaymiz
                int16_t fullPwm = ((int16_t)motorPwmRaw) * 2;
                
                actuators.setSteeringAngle(steerOffset);
                actuators.setMotorSpeed(fullPwm);

                if (mode == 0xFF) { // Reset Yaw buyrug'i
                    sensors.resetYaw();
                }
            }
        } else {
            Serial.read(); // Sinxronizatsiya buzilsa, keyingi baytga o'tish
        }
    }
}

void setup() {
    Serial.begin(SERIAL_BAUD);
    actuators.init();
    sensors.init();
}

void loop() {
    // 1. Datchiklarni yangilash (Yaw integratsiyasi va masofalar)
    sensors.update();

    // 2. Raspberry Pi buyruqlarini qabul qilish
    processIncomingCommand();

    // 3. 50 Hz tezlikda Raspberry Pi ga telemetriya yuborish
    if (millis() - lastTelemetryTime >= TELEMETRY_INTERVAL_MS) {
        lastTelemetryTime = millis();
        sendTelemetry();
    }
}

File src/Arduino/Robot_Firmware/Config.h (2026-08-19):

#ifndef CONFIG_H
#define CONFIG_H

#include <Arduino.h>

// ================= UART PARAMETRLARI =================
#define SERIAL_BAUD         115200
#define PACKET_START_BYTE   0xAA
#define TELEMETRY_START_BYTE 0xBB

// ================= SERVO (RUL BOSHQARUVI) =================
#define SERVO_PIN           9
#define SERVO_CENTER_ANGLE  90
#define SERVO_MAX_LEFT      55
#define SERVO_MAX_RIGHT     125

// ================= TB6612FNG MOTOR DRAYVERI =================
#define MOTOR_PWMA          5    // PWM tezlik pini
#define MOTOR_AIN1          7    // Yo'nalish 1
#define MOTOR_AIN2          8    // Yo'nalish 2
#define MOTOR_STBY          6    // Standby (HIGH bo'lishi shart)

// ================= 3X ULTRATOVUSH (HC-SR04) =================
// Chap sensor
#define SONAR_LEFT_TRIG     12
#define SONAR_LEFT_ECHO     11

// Markaziy (old) sensor
#define SONAR_CENTER_TRIG   4
#define SONAR_CENTER_ECHO   3

// O'ng sensor
#define SONAR_RIGHT_TRIG    A0
#define SONAR_RIGHT_ECHO    A1

#define SONAR_MAX_DISTANCE_CM 200
#define SONAR_TIMEOUT_US     (SONAR_MAX_DISTANCE_CM * 58)

// ================= LSM6DSOX GIROSKOP (I2C) =================
#define LSM6DSOX_I2C_ADDR   0x6A // Yoki 0x6B
#define LSM6DSOX_CTRL2_G    0x11
#define LSM6DSOX_OUTZ_L_G   0x26

#endif

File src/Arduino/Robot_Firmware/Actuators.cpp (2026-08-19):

#include "Actuators.h"

Actuators actuators;

void Actuators::init() {
    // Servoni biriktirish
    steeringServo.attach(SERVO_PIN);
    steeringServo.write(SERVO_CENTER_ANGLE);

    // Motor pinlarini sozlash
    pinMode(MOTOR_PWMA, OUTPUT);
    pinMode(MOTOR_AIN1, OUTPUT);
    pinMode(MOTOR_AIN2, OUTPUT);
    pinMode(MOTOR_STBY, OUTPUT);

    digitalWrite(MOTOR_STBY, HIGH); // Drayverni faollashtirish
    setMotorSpeed(0);
}

void Actuators::setSteeringAngle(int8_t targetAngleOffset) {
    int angle = SERVO_CENTER_ANGLE + targetAngleOffset;
    angle = constrain(angle, SERVO_MAX_LEFT, SERVO_MAX_RIGHT);
    steeringServo.write(angle);
}

void Actuators::setMotorSpeed(int16_t pwmSpeed) {
    pwmSpeed = constrain(pwmSpeed, -255, 255);

    if (pwmSpeed > 0) {
        // Oldinga
        digitalWrite(MOTOR_AIN1, HIGH);
        digitalWrite(MOTOR_AIN2, LOW);
        analogWrite(MOTOR_PWMA, pwmSpeed);
    } else if (pwmSpeed < 0) {
        // Orqaga
        digitalWrite(MOTOR_AIN1, LOW);
        digitalWrite(MOTOR_AIN2, HIGH);
        analogWrite(MOTOR_PWMA, abs(pwmSpeed));
    } else {
        // To'xtash (Brake)
        digitalWrite(MOTOR_AIN1, LOW);
        digitalWrite(MOTOR_AIN2, LOW);
        analogWrite(MOTOR_PWMA, 0);
    }
}

void Actuators::emergencyStop() {
    setMotorSpeed(0);
    setSteeringAngle(0);
}

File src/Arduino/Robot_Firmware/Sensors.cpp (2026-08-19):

#include "Sensors.h"

Sensors sensors;

void Sensors::init() {
    Wire.begin();
    
    // Sonar pinlari
    pinMode(SONAR_LEFT_TRIG, OUTPUT);
    pinMode(SONAR_LEFT_ECHO, INPUT);
    pinMode(SONAR_CENTER_TRIG, OUTPUT);
    pinMode(SONAR_CENTER_ECHO, INPUT);
    pinMode(SONAR_RIGHT_TRIG, OUTPUT);
    pinMode(SONAR_RIGHT_ECHO, INPUT);

    // LSM6DSOX Giroskopni 104Hz / 2000 dps rejimida ishga tushirish
    Wire.beginTransmission(LSM6DSOX_I2C_ADDR);
    Wire.write(LSM6DSOX_CTRL2_G);
    Wire.write(0x4C); // 104 Hz ODR, 2000 dps
    Wire.endTransmission();

    currentYaw = 0.0f;
    lastTimeMicros = micros();
    
    calibrateGyro();
}

void Sensors::calibrateGyro() {
    float sum = 0.0f;
    const int samples = 150;
    
    for (int i = 0; i < samples; i++) {
        sum += readRawGyroZ();
        delay(5);
    }
    gyroZBias = sum / (float)samples;
}

float Sensors::readRawGyroZ() {
    Wire.beginTransmission(LSM6DSOX_I2C_ADDR);
    Wire.write(LSM6DSOX_OUTZ_L_G);
    Wire.endTransmission(false);
    Wire.requestFrom(LSM6DSOX_I2C_ADDR, 2);

    if (Wire.available() >= 2) {
        int16_t rawZ = Wire.read() | (Wire.read() << 8);
        // 2000 dps uchun sezgirlik: 70 mdps/LSB -> 0.07 dps/LSB
        return (float)rawZ * 0.070f;
    }
    return 0.0f;
}

uint8_t Sensors::readSonarCM(uint8_t trigPin, uint8_t echoPin) {
    digitalWrite(trigPin, LOW);
    delayMicroseconds(2);
    digitalWrite(trigPin, HIGH);
    delayMicroseconds(10);
    digitalWrite(trigPin, LOW);

    unsigned long duration = pulseIn(echoPin, HIGH, SONAR_TIMEOUT_US);
    if (duration == 0) return SONAR_MAX_DISTANCE_CM;
    
    uint8_t dist = duration / 58;
    return (dist > SONAR_MAX_DISTANCE_CM) ? SONAR_MAX_DISTANCE_CM : dist;
}

void Sensors::update() {
    // 1. Giroskop integratsiyasi (Yaw)
    unsigned long now = micros();
    float dt = (now - lastTimeMicros) / 1000000.0f;
    lastTimeMicros = now;

    float rawRateZ = readRawGyroZ() - gyroZBias;
    // Kichik shovqinlarni yo'qotish (Deadband)
    if (abs(rawRateZ) > 0.15f) {
        currentYaw += rawRateZ * dt;
    }

    // 2. Ultratovush datchiklarini ketma-ket o'qish (shovqin bermasligi uchun)
    distances.leftDistance   = readSonarCM(SONAR_LEFT_TRIG, SONAR_LEFT_ECHO);
    distances.centerDistance = readSonarCM(SONAR_CENTER_TRIG, SONAR_CENTER_ECHO);
    distances.rightDistance  = readSonarCM(SONAR_RIGHT_TRIG, SONAR_RIGHT_ECHO);
}

SonarData Sensors::getDistances() {
    return distances;
}

float Sensors::getYawAngle() {
    return currentYaw;
}

void Sensors::resetYaw() {
    currentYaw = 0.0f;
}

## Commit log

2026-08-19 docs(journey): add Day 3 and Day 4 logs with SSH and 3D CAD updates
2026-08-19 feat: add team photos, source codes, and 3D CAD models
2026-08-19 docs: add detailed power distribution schematic from draw.io
2026-08-19 fix: corrected heading format and added schematic image
2026-08-19 docs: finalize power schematics, update journey logs and add engineering challenges
2026-08-24 docs: push one week of progress (3D models, assembled schematics, and journal updates)
    [WRO_karkas1.dxf]
2026-08-24 docs(schematics): electronics details images added
2026-08-24 docs: upgrade BoM table with detailed technical specifications and add 18650 power source components
2026-08-24 docs: fix BoM section layout (corrected to centered images with bullet points)
2026-08-27 docs: add comprehensive hardware pinout mapping for Arduino Nano and peripheral logic

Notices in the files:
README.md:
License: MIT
